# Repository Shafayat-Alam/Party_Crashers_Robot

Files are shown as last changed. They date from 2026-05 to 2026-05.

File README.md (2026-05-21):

# Party Crasher — Autonomous Apprehension Robot

An autonomous robot that detects, pursues, and captures targets using ultrasonic sensing, servo-actuated claws, and police-themed audiovisual feedback. Designed as both an educational toy and a proof-of-concept for law enforcement robotics.

**YouTube Demo:** [https://youtu.be/K1cG0pb9A2w](https://youtu.be/K1cG0pb9A2w)

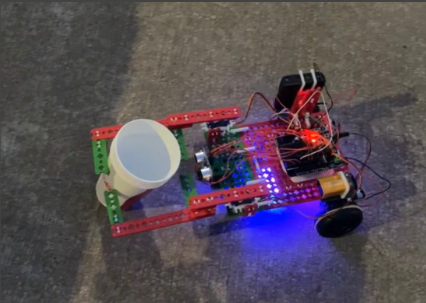
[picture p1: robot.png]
Party Crasher Robot


---

## Project Overview

**Party Crasher** is an autonomous wheeled robot that mimics law enforcement behavior through target detection, pursuit, capture, and extraction. The robot combines sensor fusion, state-machine control, and mechanical actuation to perform a complete apprehension sequence with police car-inspired lights and siren effects.

### Mission Sequence

1. **Patrol Mode** — Robot moves forward, scanning for targets with front ultrasonic sensor (blue LED indicator)
2. **Target Detection** — Object detected within 6 cm threshold triggers capture sequence
3. **Apprehension** — Servo-actuated claws close, siren activates, red/blue LEDs alternate (police effect)
4. **Extraction** — Robot reverses with captured target for 1.5 seconds
5. **Edge Detection** — Bottom ultrasonic sensor detects table edge (>10 cm ground clearance)
6. **Emergency Stop** — Robot reverses, stops, and sounds alarm (mission complete)

### Design Philosophy

**Target Application:** Educational toy demonstrating robotics concepts (sensing, actuation, control logic)  
**Proof-of-Concept:** Potential law enforcement application for non-lethal suspect apprehension

---

## System Architecture

### Hardware Components

**Locomotion:**
- 2× DC gearhead motors (rear drive)
- 4× wheels (2 driven, 2 passive front casters)
- Motor shield (eliminates H-bridge wiring complexity)

**Sensing:**
- 2× HC-SR04 ultrasonic sensors
  - **Front sensor:** Target detection (0-200 cm range)
  - **Bottom sensor:** Edge detection (ground proximity)

**Actuation:**
- 2× SG90 servo motors (180° rotation)
- Custom claw mechanism (asymmetric design)

**Feedback:**
- Piezo buzzer (siren: 700-800 Hz sweep, beeps: 50-400 Hz)
- 5× Red LEDs + 5× Blue LEDs (alternating police pattern)

**Control:**
- Arduino Uno (ATmega328P microcontroller)
- Motor shield (motor control, PWM speed control)

**Power:**
- 9V battery (Arduino/servos)
- 4× AA batteries (6V for DC motors)

---

## Mechanical Design

### Claw Mechanism

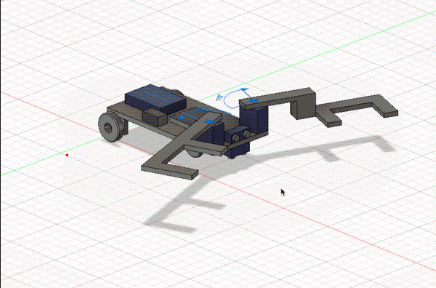
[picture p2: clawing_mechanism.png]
Claw Mechanism


*Asymmetric dual-arm design with secondary linkages for secure grip on tapered objects*

**Design Challenge:** Capture cylindrical objects (cups) with varying diameter along their height.

**Solution — Asymmetric Dual-Arm Design:**

| Feature | Implementation | Rationale |
|---|---|---|
| **Arm spacing** | Motor mounts positioned to span widest cup diameter | Ensures capture regardless of orientation |
| **Vertical offset** | Arms at different heights | Prevents collision, avoids ultrasonic obstruction |
| **Secondary links** | 2 smaller linkages per arm | Secures tapered sections arms can't reach |
| **Arm length** | Extended reach beyond sensor range | Allows capture while robot maintains forward velocity |

**Grip Sequence:**
1. Servos in released position: Left=165°, Right=15° (open)
2. Target detected (<6 cm) → servos actuate
3. Servos in locked position: Left=5°, Right=175° (closed)
4. Secondary links conform to cup taper
5. Grip maintained until extraction complete

**CAD Design:** Fusion 360 model (`Party_Crasher_v9.f3d`) demonstrates asymmetric claw geometry and servo mounting.

---

## Electronics & Wiring

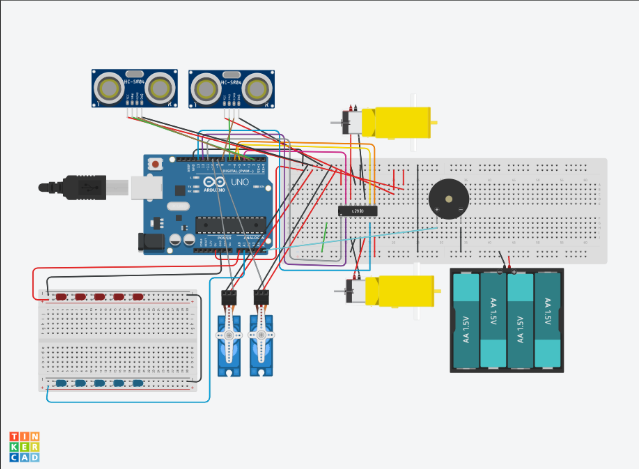
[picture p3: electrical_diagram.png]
Electrical Diagram


*Complete wiring schematic showing Arduino, motor shield, sensors, and feedback systems*

### Pin Configuration

**Motor Control (Motor Shield):**
```
Motor 1 (Right):
- Enable: Pin 6 (PWM)
- Input 1: Pin 5
- Input 2: Pin 4

Motor 2 (Left):
- Enable: Pin 11 (PWM)
- Input 1: Pin 12
- Input 2: Pin 13
```

**Servo Control:**
```
Left Servo:  Pin 10 (PWM)
Right Servo: Pin 9 (PWM)
```

**Sensors:**
```
Front Ultrasonic:
- Trig: Pin 7
- Echo: Pin 8

Bottom Ultrasonic:
- Trig: Pin 2
- Echo: Pin 3
```

**Feedback:**
```
Buzzer:    Pin A5 (analog output)
Red LEDs:  Pin A0 (via breadboard)
Blue LEDs: Pin A1 (via breadboard)
```

**Input:**
```
Start Switch: Pin 1 (digital input)
```

### Circuit Diagram

**Simplified Architecture:**

```
Arduino Uno + Motor Shield
│
├─ Motor Shield → DC Motors (6V supply)
├─ Pins 9,10 → Servo Motors (5V from Arduino)
├─ Pins 2,3,7,8 → Ultrasonic Sensors (5V logic)
├─ Pin A5 → Piezo Buzzer
├─ Pins A0,A1 → LED Arrays (breadboard)
└─ Pin 1 → Start Switch
```

**Power Distribution:**
- **Arduino/Logic:** 9V battery
- **DC Motors:** 4×AA (6V) through motor shield
- **Servos:** 5V regulated from Arduino
- **Sensors/LEDs:** 5V from Arduino

**Motor Shield Advantage:** Eliminates need for external H-bridge circuit (L298N, etc.), simplifies wiring, provides integrated PWM speed control.

---

## Software Architecture

### State Machine Control

The robot operates as a **finite state machine** with six distinct modes:

| State | Trigger | Actions | LED | Sound | Next State |
|---|---|---|-----|---|---|
| **INIT** | Power on | Grip test, release, timer setup | Blue solid | None | FORWARD |
| **FORWARD** | Default patrol | Drive forward, scan front sensor | Blue solid | Beep (400 Hz) | CUP or STOP |
| **CUP** | Front sensor <6 cm | Close grip, continue forward | Red/Blue alternate | Siren (700-800 Hz) | REVERSE |
| **REVERSE** | Cup captured | Drive backward 1.5 sec | Blue solid | Tone (150 Hz) | STOP |
| **STOP** | Timer expires or edge detected | Motors off | Red solid | Beep (500 Hz, 1 sec) | (terminal) |
| **EDGE_DETECTED** | Bottom sensor >10 cm | Emergency reverse, stop | Red solid | Beep | STOP |

**State Transition Logic:**

```cpp
// Simplified control flow
if (mode == "forward") {
    forward();
    if (cmFront < 6) → mode = "cup";
    if (cmBottom > 10) → mode = "stop" (emergency);
}

if (mode == "cup") {
    gripLock();
    if (cmFront >= 6) → mode = "reverse";
}

if (mode == "reverse") {
    reverse();
    if (reverseTimer.tick()) → mode = "stop";
}
```

---

### Object-Oriented Code Structure

**Custom Classes:**

**1. Timer Class**
```cpp
class Timer {
    double timeout, start;
    void reset();
    void setTimeout(double t);
    bool tick();  // Returns true when timeout expires
    double elapsed();
};
```
**Purpose:** Non-blocking timing for state transitions, LED blinks, audio patterns

**2. LEDHandler Class**
```cpp
class LEDHandler {
    const int LED_RED = A0;
    const int LED_BLUE = A1;
    void LED_TOGGLE_BLINK();  // Alternates red/blue every 100ms
    void RED_ON(), BLUE_ON(), LED_OFF();
};
```
**Purpose:** Police car light effect (alternating red/blue pattern)

**3. Siren Class**
```cpp
class Siren {
    int frequency;  // 700-800 Hz sweep
    void start(), stop();
    void play();    // Frequency ramps up/down for siren effect
};
```
**Purpose:** Police siren audio (frequency modulation 700→800→700 Hz)

**4. Beep Class**
```cpp
class Beep {
    int frequency;
    void setFrequency(int f);
    void setTimeout(int t1, int t2);
    void play();  // Timed beep pattern
};
```
**Purpose:** Status indication (forward mode: 400 Hz, stop mode: 500 Hz)

---

### Core Functions

**Motion Control:**
```cpp
void forward()  // Both motors forward
void reverse()  // Both motors backward
void left()     // Differential: left back, right forward
void right()    // Differential: right back, left forward
void stop()     // All motors off
```

**Servo Control:**
```cpp
void gripLock()     // Close claws: Left=5°, Right=175°
void gripRelease()  // Open claws: Left=165°, Right=15°
```

**Ultrasonic Sensing:**
```cpp
double get_duration(int trig, int echo) {
    // Send 10µs trigger pulse
    // Measure echo pulse width
    return microsecondsToCentimeters(pulseIn(echo, HIGH));
}
```

**Distance Calculation:**
```cpp
// Speed of sound: 343 m/s
// Time for round trip: t = 2d/v
double microsecondsToCentimeters(double µs) {
    return µs / 29 / 2;  // Empirical calibration
}
```

---

### Control Flow

**Main Loop Logic:**

```cpp
void loop() {
    // Read sensors
    cmFront = get_duration(trigFront, echoFront);
    cmBottom = get_duration(trigBottom, echoBottom);
    
    // Edge detection (priority)
    if (cmBottom > 10 && mode == "forward") {
        reverse();
        delay(1500);
        stop();
        mode = "stop";
    }
    
    // Target detection
    if (cmFront < 6) {
        gripLock();
        siren.start();
        led_handler.LED_TOGGLE_BLINK();
        mode = "cup";
    }
    
    // State machine execution
    switch(mode) {
        case "forward":
            forward();
            beep.play();
            break;
        case "reverse":
            reverse();
            tone(buzzer, 150);
            if (reverseTimer.tick()) mode = "stop";
            break;
        case "stop":
            stop();
            beep.play();
            break;
    }
    
    siren.play();  // Updates frequency sweep if active
}
```

**Key Features:**
- **Non-blocking timing:** All delays handled through `Timer.tick()` checks
- **Sensor polling:** 20 Hz ultrasonic sampling (50 ms loop period)
- **Priority logic:** Edge detection overrides other states (safety)

---

## Bill of Materials

### Electronics

| Qty | Component | Part Number | Purpose |
|-----|---|---|---|
| 1 | Arduino Uno | ATmega328P | Main controller |
| 1 | Motor Shield | N/A | DC motor driver (H-bridge replacement) |
| 2 | DC Gearhead Motor | N/A | Locomotion (rear wheels) |
| 2 | Servo Motor | SG90 | Claw actuation (180° rotation) |
| 2 | Ultrasonic Sensor | HC-SR04 | Distance measurement (0-200 cm) |
| 1 | Piezo Buzzer | N/A | Audio feedback (siren, beeps) |
| 5 | Red LED | N/A | Police light effect |
| 5 | Blue LED | N/A | Police light effect |
| 1 | 9V Battery | N/A | Arduino power |
| 4 | AA Battery (1.5V) | N/A | Motor power (6V total) |
| 1 | 400-pin Breadboard | N/A | LED wiring |
| 8 | Male-Female Wire | N/A | Sensor connections |
| 14 | Male-Male Wire | N/A | Breadboard connections |
| 2 | Rubber Band | N/A | Cable management |

### Mechanical (SnappyXO Components)

| Qty | Component | Purpose |
|-----|---|---|
| 4 | Outer Wheel | Drive wheels (2) + caster wheels (2) |
| 2 | Inner Wheel | Motor shaft mounting |
| 2 | 2" O-Ring Tire | Wheel traction |
| 2 | Circular Rod 1" | Claw linkages |
| 2 | Circular Rod 2.5" | Claw linkages |
| 2 | 4X Channel Plate | Main chassis platform |
| 1 | 3X Channel Plate | Chassis support |
| 9 | 3X Beam | Structural framework |
| 9 | 2X Beam | Structural framework |
| 2 | 6X Beam | Claw arms |
| 2 | 8X Beam | Claw arms |
| 1 | 4X Beam | Servo mounting |
| 2 | Servo Horn 2X | Claw attachment to servo |
| 2 | DC Motor Mount | Motor chassis attachment |
| 2 | Servo Mount | Servo chassis attachment |
| 2 | Ultrasonic Sensor Mount | Sensor positioning |
| 17 | Small H Clip | Beam connections |
| 6 | Medium H Clip | Beam connections |
| 4 | Large H Clip | Beam connections |
| 6 | L Clip | Right-angle connections |
| 13 | C Clip | Perpendicular connections |
| 4 | Small Fixed Pivot | Claw linkage pivots |
| 6 | Spacer | Platform standoffs |

**Total Component Count:** 100+ parts  
**Build Time:** ~6-8 hours (assembly + wiring + programming)

---

## Key Design Features

### 1. Sensor Fusion for Autonomous Operation

**Dual Ultrasonic Configuration:**
- **Front sensor (horizontal):** Target detection, range 0-200 cm, 6 cm trigger threshold
- **Bottom sensor (vertical):** Edge detection, >10 cm indicates no ground surface

**Sensor Placement:**
- Front sensor: 90° to chassis, unobstructed view
- Bottom sensor: Beneath platform, downward-facing

**Challenge Solved:** Single-sensor systems can't differentiate between "target in range" and "approaching table edge" — dual sensors provide context-aware decision making.

---

### 2. Mechanical Adaptability

**Asymmetric Claw Design:**

Traditional symmetric claws fail on tapered objects (cups, bottles) because:
- Upper claw contacts wide diameter → loose grip
- Lower claw contacts narrow diameter → loose grip
- Object slips through

**Solution:**
- **Upper arm:** Higher position, contacts wide section
- **Lower arm:** Lower position, contacts narrow section  
- **Secondary links:** Fill gaps, conform to taper
- **Result:** Secure grip regardless of cup orientation

**Manufacturing:** Fusion 360 CAD → 3D printed linkages or SnappyXO beam assembly

---

### 3. State Machine Robustness

**Problem:** Simple if-else logic fails when multiple conditions overlap.

**Example Failure:**
```cpp
// BAD: Race condition
if (target_detected) grip();
if (edge_detected) reverse();
// What if both are true? Grip while reversing?
```

**Solution:** Explicit state machine with priority hierarchy:
1. **Edge detection** (highest priority — safety)
2. **Target capture** (mission objective)
3. **Patrol** (default behavior)

**States are mutually exclusive** — robot can only be in one mode at a time.

---

### 4. Audio-Visual Feedback

**Police Car Simulation:**

| Mode | Sound | Lights | Purpose |
|---|---|---|---|
| Patrol | 400 Hz beep (200ms) | Blue solid | "On duty" indicator |
| Pursuit | 700-800 Hz siren sweep | Red/Blue alternate (100ms) | "In chase" effect |
| Extraction | 150 Hz tone | Blue solid | "Transporting" indicator |
| Complete | 500 Hz beep (1 sec) | Red solid | "Mission accomplished" |

**Frequency Selection:**
- Police sirens: 700-1800 Hz (actual range)
- Party Crasher: 700-800 Hz (within piezo buzzer optimal range)
- Sweep rate: 100 Hz/loop (~10 Hz modulation frequency)

---

## Technical Challenges & Solutions

### Challenge 1: Grip Timing

**Problem:** If claws close too early, robot pushes cup away. If too late, robot drives past.

**Solution:** 
- Trigger threshold: 6 cm (within claw reach)
- Continue forward motion during grip
- Servo actuation time: 500 ms (half the approach time)

**Calculation:**
```
Robot speed: ~10 cm/s
Detection range: 6 cm
Time to contact: 0.6 seconds
Servo close time: 0.5 seconds
Result: Claws fully closed before contact
```

---

### Challenge 2: Edge Detection False Positives

**Problem:** Ultrasonic sensor occasionally reads >10 cm over solid ground due to:
- Reflective surfaces
- Angled reading
- Acoustic noise

**Solution:**
- Threshold: 10 cm (conservative margin)
- Action: Immediate reverse 1.5 seconds (30 cm backstep)
- Only check during forward motion (ignored in reverse mode)

---

### Challenge 3: Motor Shield Integration

**Problem:** Traditional H-bridge (L298N) requires:
- 8 signal wires (4 per motor)
- 2 enable wires (PWM speed control)
- External power supply routing
- Complex breadboard layout

**Solution:** Arduino Motor Shield
- Direct Arduino pin mapping
- Integrated power regulation
- PWM channels pre-configured
- Cleaner wiring, fewer failure points

---

### Challenge 4: Non-Blocking Code

**Problem:** `delay()` freezes entire program — robot can't sense while waiting.

**Bad code:**
```cpp
void reverse() {
    setMotors(REVERSE);
    delay(1500);  // BLOCKED — can't detect edge!
}
```

**Solution:** Timer class with `tick()` method
```cpp
if (mode == "reverse") {
    reverse();
    if (reverseTimer.tick()) {  // Non-blocking check
        mode = "stop";
    }
    // Can still read sensors every loop iteration
}
```

---

## Code Architecture Highlights

### Class Design: Timer

**Purpose:** Replace blocking `delay()` with non-blocking timing.

**Key Methods:**
```cpp
void setTimeout(double ms);  // Set countdown duration
void reset();                // Restart timer from current time
bool tick();                 // Check if timeout expired (auto-resets)
double elapsed();            // Time since last reset
```

**Usage Pattern:**
```cpp
Timer reverseTimer;
reverseTimer.setTimeout(1500);  // 1.5 seconds

// In loop():
if (reverseTimer.tick()) {
    // Code here runs once after 1500ms
}
```

**Internal Logic:**
```cpp
bool tick() {
    bool expired = (millis() - start) > timeout;
    if (expired) start = millis();  // Auto-reset
    return expired;
}
```

---

### Class Design: LEDHandler

**Purpose:** Manage police light alternating pattern without blocking.

**Key Method:**
```cpp
void LED_TOGGLE_BLINK() {
    if (timer.tick()) {  // Every 100ms
        if (red_on) {
            RED_OFF();
            BLUE_ON();
        } else {
            BLUE_OFF();
            RED_ON();
        }
    }
}
```

**Usage:**
```cpp
LEDHandler led_handler;

// In loop():
if (mode == "cup") {
    led_handler.LED_TOGGLE_BLINK();  // Auto-alternates
}
```

**Effect:** Red/blue flashing at 5 Hz (100ms period) — visually similar to police lights.

---

### Class Design: Siren

**Purpose:** Generate frequency-swept siren sound.

**Frequency Modulation:**
```cpp
void play() {
    tone(buzzer, frequency);
    frequency += frequency_k;  // Ramp up or down
    
    if (frequency < 700 || frequency > 800) {
        frequency_k *= -1;  // Reverse direction
    }
}
```

**Audio Characteristics:**
- Range: 700-800 Hz (100 Hz sweep)
- Period: ~1 second full cycle
- Waveform: Triangle wave (linear ramp)

---

## Operation Guide

### Setup

1. **Power connection:**
   - Insert 9V battery → Arduino
   - Insert 4× AA batteries → motor pack
   - Switch on Arduino

2. **Initial state:**
   - Claws perform grip test (open → close → open)
   - Blue LED turns on (ready state)

3. **Placement:**
   - Position robot on flat surface
   - Ensure >30 cm clearance in front
   - Place target (cup) 10-50 cm ahead

4. **Start:**
   - Robot begins patrol automatically
   - Front sensor scans for obstacles

---

### Behavioral Sequence

**Phase 1: Patrol**
- Forward motion (~10 cm/s)
- Blue LED solid
- 400 Hz beep every 200ms
- Scanning range: 0-200 cm

**Phase 2: Target Acquired (cmFront < 6 cm)**
- Claws close (500ms actuation)
- Siren activates (700-800 Hz sweep)
- Red/blue LEDs alternate (100ms period)
- Continue forward motion

**Phase 3: Extraction (cup secured)**
- Reverse motion (1.5 seconds = ~15 cm)
- 150 Hz tone
- Blue LED solid
- Claws remain closed

**Phase 4: Mission Complete**
- Stop all motors
- 500 Hz beep (1 second pulse)
- Red LED solid
- Claws release

**Emergency: Edge Detected (cmBottom > 10 cm)**
- Immediate reverse (1.5 seconds)
- Stop
- Red LED + beep pattern
- Overrides all other states

---

## Future Improvements

### Hardware Enhancements

1. **IMU Integration** (MPU6050)
   - Gyroscope for turn rate control
   - Accelerometer for impact detection
   - Enables controlled turns, collision response

2. **Camera Vision** (OpenMV or ESP32-CAM)
   - Replace ultrasonic with object recognition
   - Color-based target selection
   - Face/shape detection

3. **Encoders on Motors**
   - Precise distance traveled measurement
   - Speed feedback for PID control
   - Odometry for dead reckoning

4. **Force Sensing in Claws**
   - FSR (force-sensitive resistor) in grip pads
   - Adaptive grip strength
   - Prevents crushing fragile objects

---

### Software Enhancements

1. **PID Motor Control**
   - Replace binary motor states with PWM speed control
   - Smooth acceleration/deceleration
   - Maintain constant speed regardless of terrain

2. **Kalman Filtering on Sensors**
   - Reduce ultrasonic noise
   - Fuse IMU + ultrasonic data
   - More reliable edge detection

3. **Behavior Tree Architecture**
   - Replace state machine with modular behavior tree
   - Easier to add new behaviors
   - Priority-based task execution

4. **Remote Telemetry**
   - Bluetooth/WiFi status reporting
   - Real-time sensor visualization
   - Manual override capability

---

### Mechanical Enhancements

1. **Omnidirectional Wheels (Mecanum)**
   - Strafe sideways to align with target
   - Reduces capture failure rate
   - More complex motor control

2. **Spring-Loaded Grip**
   - Passive compliance in claws
   - Absorbs shock during capture
   - Reduces motor stall risk

3. **Adjustable Wheelbase**
   - Telescoping chassis
   - Adapt to different target sizes
   - Improved stability

---

## Educational Value

### Concepts Demonstrated

| Concept | Implementation | Learning Outcome |
|---|---|---|
| **Sensing** | Ultrasonic time-of-flight | Distance measurement principles |
| **Actuation** | Servo + DC motor control | Difference between position and velocity control |
| **Control Logic** | State machine design | Software architecture for robotics |
| **Real-Time Systems** | Non-blocking timing | Event-driven programming |
| **Object-Oriented Design** | C++ classes | Code modularity and reusability |
| **Sensor Fusion** | Dual ultrasonic interpretation | Context from multiple sources |
| **Mechanical Design** | Asymmetric linkage | Adaptation to non-uniform geometry |
| **Power Systems** | Dual battery configuration | Isolation of logic and motor power |

---

## Applications

**Educational:**
- STEM curriculum: robotics, programming, mechanical design
- Competition platform: RoboGames, FIRST Robotics concepts
- Interactive demonstration: school fairs, museum exhibits

**Research:**
- Non-lethal apprehension study
- Human-robot interaction (toy vs. utility perception)
- Autonomous capture mechanism benchmarking

**Consumer:**
- Pet toy (chase and capture mode)
- Security demonstration (intrusion response)
- Interactive party game ("catch the robot")

---

## Project Files

```
Party-Crasher/
├── robot_code.ino              # Arduino source code
├── Party_Crasher_v9.f3d        # Fusion 360 CAD model
├── robot.png                   # Assembled robot photo
├── electrical_diagram.png      # Wiring schematic
├── clawing_mechanism.png       # Claw mechanism close-up
└── README.md                   # This file
```

**Circuit Simulation:** [TinkerCAD Link](https://www.tinkercad.com/things/8K58ceJHaWl)

---

## Technical Specifications Summary

| Parameter | Specification |
|---|---|
| **Dimensions** | ~25 cm × 20 cm × 15 cm (L×W×H) |
| **Weight** | ~1.5 kg (estimated) |
| **Speed** | ~10 cm/s forward, ~8 cm/s reverse |
| **Detection Range** | 6-200 cm (front ultrasonic) |
| **Edge Detection** | >10 cm (bottom ultrasonic) |
| **Grip Closure Time** | 500 ms |
| **Grip Width** | 5-15 cm (adjustable via servo angle) |
| **Battery Life** | ~2 hours continuous operation |
| **Operating Surface** | Flat, hard surfaces (no carpet) |
| **Target Capacity** | Cylindrical objects, 200-500g, 5-10 cm diameter |

---

## Lessons Learned

### What Worked Well

1. **Motor shield simplicity** — Eliminated H-bridge wiring complexity, reduced failure points
2. **State machine clarity** — Easy to debug, clear behavioral logic
3. **Asymmetric claw design** — Consistently captured tapered objects
4. **Non-blocking timers** — Smooth multi-tasking without threading

### What Could Be Improved

1. **Sensor noise** — Ultrasonic occasionally misreads; Kalman filter would help
2. **Motor speed** — Binary on/off; PWM speed control would smooth motion
3. **Claw force** — No feedback; some objects crushed, others slipped
4. **Turn control** — No gyroscope; turns are imprecise

### Key Takeaways

- **Mechanical constraints drive software design** — Claw actuation time determined sensor trigger threshold
- **Sensor fusion is essential** — Single ultrasonic would confuse edge/target scenarios
- **State machines prevent race conditions** — Explicit mode prevents conflicting actions
- **User feedback is critical** — LEDs and sound made behavior interpretable

---

## Acknowledgments

**Hardware:** SnappyXO robotics kit  
**Development Environment:** Arduino IDE 1.8.19  
**CAD Software:** Autodesk Fusion 360  
**Circuit Simulation:** TinkerCAD  

**Special Thanks:** MEC 310 — Robotics course, Stony Brook University

---

## License

This project is open-source for educational purposes. Feel free to modify, improve, and share.

---

**Status:** ✅ Fully Operational — Video demonstration available on YouTube

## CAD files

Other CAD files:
Party Crasher v9.f3d

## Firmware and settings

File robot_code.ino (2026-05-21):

// #include <NewPing.h>


#include <Servo.h>


// pin constants definition
const int motorOne_InputTwo = 4;
const int motorOne_InputOne = 5;
const int motorOne_Enable = 6;


const int motorTwo_Enable = 11;
const int motorTwo_InputOne = 12;
const int motorTwo_InputTwo = 13;


const int trigFront = 7;
const int echoFront = 8;
const int trigBottom = 2;
const int echoBottom = 3;


const int SWITCH = 1;


const int buzzer = A5;


// objects initialization
Servo servoLeft;
Servo servoRight;


// state variables
String gripStatus = "released";
String mode = "forward";
bool started = false;
int min = 999;


class Timer {
public:
  double timeout;
  double start;
  Timer() {
    timeout = 0;
    start = millis();
  }


  void reset() {
    start = millis();
  }


  void setTimeout(double t) {
    timeout = t;
  }
  double elapsed() {
    return millis() - start;
  }
  bool tick() {
    bool ticked = millis() - start > timeout;
    if (ticked) {
      start = millis();
    }
    return ticked;
  }
};


class LEDHandler {
public:
  const int LED_RED = A0;
  const int LED_BLUE = A1;
  bool red_on = false;
  bool blue_on = false;
  Timer timer;
  LEDHandler() {
    pinMode(LED_RED, OUTPUT);
    pinMode(LED_BLUE, OUTPUT);
    timer.setTimeout(100);
    Serial.println("LED Handler Initialized");
  }


  void LED_OFF() {
    digitalWrite(LED_RED, LOW);
    digitalWrite(LED_BLUE, LOW);
  }


  void LED_ON() {
    digitalWrite(LED_RED, HIGH);
    digitalWrite(LED_BLUE, HIGH);
  }


  void RED_ON() {
    digitalWrite(LED_RED, HIGH);
    red_on = true;
  }
  void BLUE_ON() {
    digitalWrite(LED_BLUE, HIGH);
    blue_on = true;
  }
  void RED_OFF() {
    digitalWrite(LED_RED, LOW);
    red_on = false;
  }
  void BLUE_OFF() {
    digitalWrite(LED_BLUE, LOW);
    blue_on = false;
  }


  bool LEDS_ON() {
    return red_on && blue_on;
  }


  void LED_TOGGLE_BLINK() {
    if (LEDS_ON()) {
      BLUE_OFF();
    }
    if (timer.tick()) {
      if (red_on) {
        RED_OFF();
        BLUE_ON();
      } else {
        BLUE_OFF();
        RED_ON();
      }
    }
  }
};


class Siren {
public:
  int frequency;
  int frequency_k = 2;
  bool playing = false;
  Timer timer;
  Siren() {
    frequency = 700;
    timer.setTimeout(15);
  }


  isPlaying() {
    return playing;
  }


  void start() {
    playing = true;
  }


  void play() {
    if (!playing) {
      return;
    } else {
      tone(buzzer, frequency);
      frequency += frequency_k;
    }
    if (frequency < 700 || frequency > 800) {
      frequency_k *= -1;
    }
    // if (timer.tick()) {
    //   frequency += frequency_k;
    // }
    Serial.println(frequency);
  }


  void stop() {
    playing = false;
    noTone(buzzer);
  }
};


class Beep {
public:
  int frequency;
  int timeout;
  Timer timer, soundTimer;
  bool playing = false;
  LEDHandler led;


  Beep() {
    frequency = 50;
    timeout = 100;
    timer.setTimeout(timeout);
    soundTimer.setTimeout(50);
  }
  void setFrequency(int f){
    frequency = f;
  }


  void setTimeout(int t1, int t2) {
    timeout = t1;
    timer.setTimeout(timeout);
    soundTimer.setTimeout(t2);
  }
  void play() {
    if (!playing && timer.tick()) {
      playing = true;
      soundTimer.reset();
    } else {
      if (playing) {
        tone(buzzer, frequency);
        led.RED_ON();        
        if (soundTimer.tick()) {
          playing = false;
          timer.reset();
          noTone(buzzer);
          led.RED_OFF();
        }
      }
    }
  }
};


LEDHandler led_handler;
Siren siren;
// NewPing sonar(trigFront, echoFront, 200);


void setup() {
  Serial.begin(9600);
  for (int i = 4; i <= 10; i++) {
    if (i == 8)
      continue;
    pinMode(i, OUTPUT);
  }
  pinMode(SWITCH, INPUT);
  pinMode(buzzer, OUTPUT);
  pinMode(trigFront, OUTPUT);
  pinMode(echoFront, INPUT);
  pinMode(trigBottom, OUTPUT);
  pinMode(echoBottom, INPUT);
  pinMode(6, OUTPUT);
  pinMode(11, OUTPUT);
  // digitalWrite(motorOne_Enable, HIGH);
  // digitalWrite(motorTwo_Enable, HIGH);
  servoLeft.attach(10);
  servoRight.attach(9);
  gripRelease();
  // siren.start();
}
void forward() {
  // Serial.println("Forward");
  digitalWrite(motorOne_InputOne, HIGH);
  digitalWrite(motorOne_InputTwo, LOW);
  digitalWrite(motorTwo_InputOne, LOW);
  digitalWrite(motorTwo_InputTwo, HIGH);
  // digitalWrite(motorOne_Enable, 0);
  // digitalWrite(motorTwo_Enable, 0);
}
void right() {
  // Serial.println("Turn Right");
  digitalWrite(motorOne_InputOne, HIGH);
  digitalWrite(motorOne_InputTwo, LOW);
  digitalWrite(motorTwo_InputOne, HIGH);
  digitalWrite(motorTwo_InputTwo, LOW);
}
void left() {
  // Serial.println("Turn Right");
  digitalWrite(motorOne_InputOne, LOW);
  digitalWrite(motorOne_InputTwo, HIGH);
  digitalWrite(motorTwo_InputOne, LOW);
  digitalWrite(motorTwo_InputTwo, HIGH);
}
void reverse() {
  // Serial.println("Reverse");
  digitalWrite(motorOne_InputOne, LOW);
  digitalWrite(motorOne_InputTwo, HIGH);
  digitalWrite(motorTwo_InputOne, HIGH);
  digitalWrite(motorTwo_InputTwo, LOW);
}


void stop() {
  // Serial.println("Reverse");
  digitalWrite(motorOne_InputOne, LOW);
  digitalWrite(motorOne_InputTwo, LOW);
  digitalWrite(motorTwo_InputOne, LOW);
  digitalWrite(motorTwo_InputTwo, LOW);
}




long microsecondsToInches(double microseconds) {
  return microseconds / 74 / 2;
}


double microsecondsToCentimeters(double microseconds) {
  return microseconds / 29 / 2;
}


void gripLock() {
  if (gripStatus == "locked") {
    return;
  }
  int d = 50;
  int offset = 5;
  // for (int i = offset; i < 180 - offset; i++){
  //   servoLeft.write(180 - offset - i);
  //   servoRight.write(i);
  //   delay(d);
  // }
  servoLeft.write(offset);
  servoRight.write(180 - offset);
  // delay(500);
  stop();
  gripStatus = "locked";
  delay(500);
}


void gripRelease() {
  if (gripStatus == "released") {
    return;
  }
  int d = 50;
  int offset = 15;
  servoLeft.write(180 - offset);
  servoRight.write(offset);
  // delay(500);
  gripStatus = "released";
}




double get_duration(int trig, int echo) {
  // return 1;
  pinMode(trig, OUTPUT);
  digitalWrite(trig, LOW);
  delay(5);
  digitalWrite(trig, HIGH);
  delay(10);
  digitalWrite(trig, LOW);
  pinMode(echo, INPUT);
  // return 1;
  return microsecondsToCentimeters(pulseIn(echo, HIGH));
}


bool switch_pressed() {
  return digitalRead(SWITCH);
}


Timer reverseTimer;
Beep beep;
// scanTimer.setTimeout(1000);


void loop() {
  {
    if (!started) {
      gripLock();
      Serial.println(switch_pressed());
      led_handler.BLUE_ON();
      gripRelease();
      // scanTimer.setTimeout(1000);
      // siren.play();
      reverseTimer.setTimeout(1500);
      started = true;
      beep.setFrequency(400);
      beep.setTimeout(200, 100);
    }
    // analogWrite(motorOne_Enable, 0);     //allows motor one&#39;s speed to go
    // analogWrite(motorTwo_Enable, 0);     //allows motor two&#39;s speed to go
    double duration, cmFront, cmBottom;  //establishes variables for duration of ping
    cmFront = get_duration(trigFront, echoFront);
    cmBottom = get_duration(trigBottom, echoBottom);


    // Serial.println(cmBottom);
    // beep.play();
    // return;
    if (mode == "forward" || mode == "cup") {
      forward();
      if (cmBottom > 10) {
        led_handler.LED_OFF();
        led_handler.RED_ON();
        reverse();
        delay(1500);
        mode = "stop";
        stop();
        delay(1000);
      }
    }
    if (mode == "forward" && mode != "cup"){
      beep.play();
    }
    if (mode == "stop") {
      stop();
      beep.play();
      return;
    }
    if (cmFront < 6) {
      gripLock();
      // led_handler.LED_OFF();
      // tone(buzzer, 100);
      siren.start();
      led_handler.LED_TOGGLE_BLINK();
      mode = "cup";
    } else {
      gripRelease();
      if (mode == "cup") {
        mode = "reverse";
        reverseTimer.reset();
        siren.stop();
        tone(buzzer, 50);
      } else {
        // led_handler.LED_OFF();
        led_handler.BLUE_ON();
        // mode = "forward";
      }
    }
    if (mode == "reverse") {
      reverse();
      tone(buzzer, 150);
      if (reverseTimer.tick()) {
        Serial.println("Tickkkkkkkkkkk");
        // int a = 1 / 0;
        mode = "stop";
        beep.setTimeout(500, 1000);
        noTone(buzzer);
      }


    }
    Serial.println(mode);
    siren.play();
  }
}
